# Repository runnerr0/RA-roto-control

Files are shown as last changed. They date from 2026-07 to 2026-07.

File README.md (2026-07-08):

# RA Roto Control

Networked motor-speed controller for **Radiant Atmospheres**. Show-control protocols
(**DMX512, Art-Net, sACN/E1.31**) feed an **ESP32-POE-ISO** that translates them to **RS232 serial**
commands driving a **Roboteq HDC2450** brushed-DC motor controller — with a web interface for setup, DMX
personas, network config, live telemetry, and manual override. Sibling project to [raDMX](../raDMX).

**Everything drives the motor over serial** — and it has proven to be an excellent control interface.
One signed command (`!G 1 <-1000..+1000>`) is speed *and* direction, the controller's own command-loss
watchdog self-stops the motor if the sender goes silent, and it streams back real telemetry (amps,
volts, temp, faults) — all with **no DAC, op-amp, or calibration**. That's why the whole design
converges on one path:

```
DMX512 / Art-Net / sACN ─► ESP32-POE-ISO ─► RS232 serial (!G) ─► HDC2450 ─► roto motor
```

The [host control console](tools/roto-bench/README.md) already drives that serial link on real hardware;
the ESP32 is the networked front-end that will feed the same serial path (a follow-up, pending parts).

## What it does

```
DMX512 / Art-Net / sACN ─► ESP32-POE-ISO ─► MAX3232 ─► RS232 ─► HDC2450 ─► roto motor
                                │  ◄── telemetry (amps, volts, temp, faults) ──┘
                                └──── web UI: config · personas · override · diagnostics
```

- **One motor**, commanded over serial: `!G 1 <-1000..+1000>` — one signed value is speed **and**
  direction (0 = stop). No DAC, no op-amp, no calibration.
- **DMX personas** incl. **ultra-slow modes** (compressed command ranges) + a live **multiplier**.
  See [`docs/PERSONAS.md`](docs/PERSONAS.md).
- **Wired Ethernet + PoE + galvanic isolation** (Olimex ESP32-POE-ISO) for rugged festival deployment.
- **Layered fail-safe** — the HDC2450's own `^RWD` command-loss watchdog stops the motor if the ESP32
  goes silent (works on serial, unlike analog), backed by firmware STOP + slew limiting.
- **Real telemetry** — motor amps, battery voltage, temperature, and fault flags in the web dashboard.

## Hardware

- **Host:** Olimex ESP32-POE-ISO
- **Motor controller:** Roboteq HDC2450 (Motor 1 channel)
- **Link:** ESP32 UART → MAX3232 → HDC2450 RS232 (DB25 pins 2/3), shared ground on pin 5
- **Optional:** KF0602D SSR for remote power-enable; MAX485 + XLR for physical DMX512 input

Full pinout, wiring diagram, BOM, and bring-up checklist: [`docs/HARDWARE.md`](docs/HARDWARE.md).

## Firmware

PlatformIO + Arduino-ESP32. Serial control core, Art-Net/sACN parsers, layered fail-safe, and a minimal
async web dashboard — **compiles clean** for the ESP32-POE-ISO (RAM 13.6%, Flash 67.9%).

```bash
cd firmware
pio run -e olimex_poe_iso            # build
pio run -e olimex_poe_iso -t upload  # flash
```

## Host tools (bench / bring-up)

Python tools that talk to the HDC2450 directly over USB — no ESP32 required — for commissioning and
bench control. Require `pyserial`.

- **[`tools/roto-setup/`](tools/roto-setup/)** — config tool. Read (`--audit`) or write + verify
  (`--apply`, RAM by default) controller configuration from JSON manifests. **Config-only: never issues a
  motor command.** As-found config catalogs live under `captures/`.
- **[`tools/roto-bench/`](tools/roto-bench/)** — a full-featured web **control console** (`roto_bench.py` +
  `ui.html`). Drives Motor 1 over serial with named run modes (**JOG / CRUISE / DRIFT / HOLD**; DRIFT =
  auto slow-sweep patterns, now explicit Run/Stop) and a **HOLD/CREEP** effort control. Layered safety: arm
  toggle, an enforced-and-displayed **speed cap** in every mode, slew, browser deadman, **spacebar E-STOP**,
  a **current governor** (default on — feathers command to hold amps just under the limit instead of
  tripping), a **soft-stop** that halts every mode (incl. DRIFT), plus **overcurrent/stall + temperature +
  I²t auto-trip** and **control-drift detection**. UI is in **percentages** with center-zero sliders,
  comprehensive hover-help, and an operator guide at `/guide`; **pop-out** dashboards (`/graphs`, `/stats`)
  drive a second screen, `--lan` + `/remote` give a phone view, and **config backup/restore** snapshots the
  controller. A **`--sim` preview mode** runs the whole UI with no hardware. **Also a viable standalone
  run-time control path** for a self-contained piece — see [`tools/roto-bench/README.md`](tools/roto-bench/README.md).
- **[`tools/as5600-reader/`](tools/as5600-reader/)** — optional AS5600 magnetic-encoder add-on for
  **closed-loop** feedback. A small Arduino/ESP32 (`as5600_reader.ino`) bridges the I²C encoder to USB
  serial; the console reads real **fixture RPM** (shaft RPM ÷ a configurable gear ratio) and adds a
  **TRUE STALL** trip (commanded but the shaft isn't turning — a check open-loop current alone can't make).
  Ships with a parametric 3D-printed nested self-spacing mount (`as5600_mount.scad` + STLs). See
  [`tools/as5600-reader/README.md`](tools/as5600-reader/README.md).

```bash
pip install pyserial
python3 tools/roto-setup/roto_setup.py --audit      # read controller config (safe)
python3 tools/roto-bench/roto_bench.py              # web console at http://127.0.0.1:8791
python3 tools/roto-bench/roto_bench.py --sim        # try the whole UI with no hardware
```

> **Safety:** the bench console commands a real 2×150 A motor controller. Power the motor from a
> current-limited supply, keep the controller's hardware E-stop reachable, and read
> [`tools/roto-bench/`](tools/roto-bench/) before first use.

## Docs

| Doc | Contents |
|-----|---|
| [`CLAUDE.md`](CLAUDE.md) | Project guide, locked decisions, operational rules |
| [`docs/HARDWARE.md`](docs/HARDWARE.md) | Pinout, MAX3232 wiring, BOM, bring-up checklist |
| [`docs/PERSONAS.md`](docs/PERSONAS.md) | DMX persona definitions + command scaling |
| [`docs/ARCHITECTURE.md`](docs/ARCHITECTURE.md) | Firmware module map, protocols, safety model, roadmap |

## Status

**Serial control + safety proven on hardware — via the host console.** The
[control console](tools/roto-bench/README.md) has matured into a full-featured run-time control surface:
Motor 1 runs over `!G` behind a current governor, soft-stop, an enforced speed cap, and layered auto-trip
protection (overcurrent/stall, temperature, I²t) plus control-drift detection. The optional
[AS5600 encoder](tools/as5600-reader/README.md) adds closed-loop RPM feedback and a true-stall trip.
Telemetry, `ALIM`/`ATGA` config, and the `^RWD` watchdog are all validated. New console/encoder features
are proven in `--sim` and on the bench; the legacy DMX→analog rig is reverse-engineered in
[`docs/LEGACY-WIRING.md`](docs/LEGACY-WIRING.md).

The **ESP32-POE-ISO firmware** (the product — adds Ethernet/PoE + DMX/Art-Net/sACN) compiles clean;
next step is porting the proven console logic into firmware. See [`docs/ARCHITECTURE.md`](docs/ARCHITECTURE.md).

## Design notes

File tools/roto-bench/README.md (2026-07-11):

# RA Roto — Control Console (`roto-bench`)

A host-side (macOS / Linux) web console that drives the **Roboteq HDC2450, Motor 1**, directly over
USB serial — **no ESP32 required**. It began as a bench bring-up instrument and has grown into a
**viable standalone run-time control path** for a self-contained rotating piece (see
[Running from this console](#running-the-show-from-this-console)).

```
browser (localhost:8791) ──HTTP──► roto_bench.py ──USB serial──► HDC2450 ──► Motor 1
        control + telemetry              (owns the port)         !G / ?… / ^…
```

stdlib + `pyserial` only, no build step:
- **`roto_bench.py`** — serial worker + web server + optional encoder reader (the engine).
- **`ui.html`** — the operator console (served at `/`).
- **`guide.html` · `graphs.html` · `stats.html` · `remote.html`** — the operator guide (`/guide`),
  pop-out live charts (`/graphs`), big telemetry tiles (`/stats`), and a touch phone view (`/remote`).

---

## Quick start

```bash
./run.sh                         # finds Python 3.6+, installs pyserial if needed, launches
# — or manually —
pip install pyserial
python3 roto_bench.py            # auto-detects the HDC2450 USB port
# open http://127.0.0.1:8791
```

It starts **DISARMED**. Pick a run mode → **ARM** → drive. Power the motor from a **current-limited
supply** and keep the controller's hardware E-stop reachable.

### Flags (all pass through `run.sh` too)

| Flag | Effect |
|---|---|
| `--port PORT` | Pin the serial port (auto-detected otherwise). |
| `--cap N` | Initial speed cap in raw command units `/1000` (default `150` = 15%). |
| `--sim` | **Preview mode** — run the whole UI on synthetic telemetry, **no hardware**. Validates logic/UI, not real motor physics. |
| `--webport N` | HTTP port (default `8791`). |
| `--host ADDR` / `--lan` | Bind address; `--lan` = `--host 0.0.0.0` to reach the console from a phone/tablet on the LAN. Prints a `/remote` URL. |
| `--encoder PORT` | Enable the optional AS5600 encoder bridge at boot (also toggle it live in the UI). |
| `--gear R` | Gear ratio — encoder-shaft revs per fixture rev (default `1.0`). |

## Compatibility (older Macs)

Designed to run on legacy machines — there's **no build step, no native code, and one pure-Python
dependency**, so CPU architecture and OS age barely matter. `run.sh` handles the fiddly parts.

| Piece | Minimum | Notes |
|---|---|---|
| **Python** | **3.6+** | `ThreadingHTTPServer` has a 3.6 fallback; only `pyserial` is required. |
| **Browser** | **Safari 10+** (2016) / any modern Chrome or Firefox | UI avoids ES2020 syntax (no `?.`/`??`) and uses `XMLHttpRequest`, so old Safari doesn't choke. |
| **Serial** | USB CDC (`/dev/cu.usbmodem*`) | Auto-detected; pass `--port` to pin it. |

Kept legacy-safe deliberately: no transpiler, no framework, `ui.html` is served as-is and re-read per
request. If you touch the UI, stick to ES6 (arrow functions/template literals are fine) and avoid
`?.`, `??`, and other ES2020+ features so it keeps running on old Safari.

---

## Run modes

Pick the mode that matches what you're doing; each sets the right safety behavior for you.

| Mode | Behavior | Use for |
|---|---|---|
| **JOG** | Hold the slider to run; release = stop. | Setup, positioning, testing. |
| **CRUISE** | Set a speed; it holds. Stall-protected. | Steady running. |
| **DRIFT** | Two-phase self-running sweep (**Run/Stop** — see below). Stall-protected. | Ambient / atmospheric motion. |
| **HOLD** | Maintain position under load; stall-trip off, temperature/I²t still guard. | Holding against a load. |
| **CREEP** | Very slow under load; stall-trip off, anti-stiction kick on start. | Slow loaded creep. |

### DRIFT (two-phase, Run/Stop)
Entering DRIFT arrives **halted** — it does *not* auto-run. Set the pattern, then press **▶ Run drift**;
the global **Stop** halts it. The command is generated server-side (`/api/drift`), cycling:
hold **Side A** (`ta` s) → ramp to **Side B** (`ramp` s) → hold **Side B** (`tb` s) → ramp back → repeat.
- **Side A / Side B speed** — the two target speeds (%, center-zero: right = fwd, left = rev).
- **hold A / hold B** — seconds to dwell at each side.
- **ramp** — seconds to ease between the two sides (`0` = snap).

Every side is clamped to the **speed cap** — set the cap ≥ the larger side or the peaks clip.

---

## Safety (layered)

Fastest / most-local first — a fault stops the motor, it doesn't run it:

1. **PSU current limit** — physical, reset-proof. The real ceiling.
2. **HDC2450 `ALIM` foldback** — controller caps motor current (we run 5 A).
3. **`^RWD` watchdog** — the console streams `!G` every ~66 ms; if the process dies, the controller
   self-stops in ~0.5 s.
4. **Current governor** *(RUN modes, **default ON**)** — closed loop on motor current: feathers the
   command to hold amps just under ~0.85×`ALIM`, so the motor **rides** the ceiling instead of slamming
   it and breaking free. **While the governor is on, the stall/overcurrent trip is suppressed** — the
   governor owns current limiting; I²t + temp + `ALIM` foldback are the backstops. Toggle + "% of limit"
   in **⚙ Settings** (`/api/governor`).
5. **Stall / overcurrent trip** *(RUN modes, **only when the governor is OFF**)* — amps held near the
   limit for `trip_ms` → stop + disarm.
6. **Temperature trip** — max controller temp ≥ threshold → stop. Jam/hold agnostic.
7. **I²t overload trip** — leaky current²·time budget → stop. Catches "holding too hard, too long."
   On by default; the **I²t checkbox** in Settings → Protect disables it (the budget value is kept, the
   accumulator clears) when the proxy fights a legitimately heavy load — temperature stays the real guard.
8. **TRUE STALL trip** *(optional encoder)* — commanded ≥ 10% but the shaft reads ~0 RPM → stop.
   Suppressed in HOLD/CREEP (which legitimately sit near 0 RPM). See the encoder section.
9. **Control-drift alarm** — see below.
10. **Operator layer** — arm toggle, hold-to-run (JOG), browser deadman (JOG), speed cap + slew,
    **soft-stop latch**, **E-STOP** (button or **spacebar**).

On any trip: command → 0, motor **disarmed**, latched until the operator clears it. A red banner +
audible alarm + timestamped alert log. The command card also shows **why** output is held at 0
(DISARMED / DEADMAN / STOPPED / TRIPPED / E-STOP), so "armed but not moving" is never a mystery.

> **Soft-stop latch.** The **Stop** button (`/api/stop`) forces output to 0 in **every** mode — including
> a running DRIFT — while staying **armed**; status shows **STOPPED**. Any fresh command (slider, Go,
> Run drift) releases it. Distinct from E-STOP, which also disarms and latches.

> **Jam vs. hold:** open-loop (no encoder) can't tell a jam from a loaded hold by current alone.
> That's why RUN modes stall-trip on current while HOLD relies on temperature + I²t. The real fix is
> an encoder (closed loop) — the HDC2450 has the inputs for it.

---

## Operating the console (UI)

- **Everything command-related is in percent (0–100%)**, not raw −1000…1000.
- **Center-zero sliders** (jog + drift Side A/B) fill outward from center — green forward, amber reverse.
- **Speed cap enforced in every mode** *and* surfaced: the slider range and the exact-speed box are
  limited to the cap, and a **⚠ at speed cap** note shows when pinned. The engine also clamps to ±cap.
- **HOLD / CREEP effort control** replaces the coarse slider with a Fwd/Rev toggle + a dial scoped
  `0..cap` + fine `−5/−1/+1/+5` nudges and a large "N% fwd/rev" readout — for fine effort in the low band.
- **Arm is a toggle switch** (slides on/off), not a state-labeled button.
- **? Help** toggle in the top bar: point at any control for an inline explanation. Full operator guide
  at **`/guide`**.
- **Top bar**: status · live amps/cmd · ARM · Help · Guide · **E-STOP** (isolated far-right). Clear E-Stop
  / Reset Trip appear only when relevant. **Spacebar = E-STOP** (unless a field is focused).

## Second screen & remote access

- **⧉ Pop out** opens **`/graphs`** (live motion / current / all-telemetry charts) and **`/stats`**
  (big color-coded telemetry tiles) in their own windows — drag either to a second monitor.
- **`--lan`** (or `--host 0.0.0.0`) exposes the console on the network; **`/remote`** is a
  touch-optimized phone view (monitor + E-STOP / Arm / Stop). `--webport N` changes the port. LAN motor
  control is a deliberate security tradeoff — trusted network only.
- **`--sim`** runs the entire UI on synthetic telemetry with **no hardware** — validates logic and the
  UI, not real motor physics.

## Optional: AS5600 encoder (real motion feedback)

An **AS5600 magnetic encoder** on a small Arduino/ESP32 I²C→USB bridge adds real shaft sensing. Enable it
in **⚙ Settings → Encoder** (port + gear ratio + a live debug readout), or at boot with
`--encoder PORT --gear R`. It's a pure sensor — it never commands the motor — and it adds:

- **Fixture RPM** — shaft RPM ÷ gear ratio (the big-wheel speed).
- **TRUE STALL trip** — commanded ≥ 10% but the shaft reads ~0 RPM → stop. The motion check open-loop
  current can't make. Suppressed in HOLD/CREEP.

Endpoints `/api/encoder`, `/api/serial_ports`. Hardware, firmware, and 3D-printed mount:
[`../as5600-reader/`](../as5600-reader/) (`as5600_reader.ino`, `as5600_mount.scad`). This is the interim
toward full controller-side closed loop (encoder on the HDC2450 ENC inputs + `MMOD`).

---

## Advanced — controller profile & control drift

The **Advanced** section (collapsed by default) live-edits the HDC2450's **own** configuration —
`ALIM`, `MXPF/MXPR`, `RWD`, `ATRIG/ATGA/ATGD` — written to controller **RAM** and read back to verify.
Each parameter is described inline. `Save to flash` persists RAM → EEPROM.

**Control-drift detection.** The console continuously compares the controller's live `ALIM`, `RWD`,
`AINA 3`, `AINA 4` against an expected safe baseline. If they diverge — most commonly because a
**controller reset reverted the RAM config** back to factory (100 A limit, analog command re-enabled) —
it raises a **CONTROL DRIFT** critical alarm. **Re-apply safe profile** restores the baseline in one
click. Deliberate edits you make become the new baseline, so it only alarms on drift you didn't intend.

> RAM config is lost on any controller reset. For a run, `Save to flash` so it survives a power cycle.

**Config backup / restore.** *Config snapshot* captures the controller's **current** config as a restore
point and writes it back with one tap — instant recovery if the config drifts or a power cycle reverts it.
**Backup** also downloads a `.json`; **Load file** restores from a previously saved one. Complements
*Re-apply safe profile* (which restores the fixed safe baseline).

---

## Slow-loaded operation (CREEP + characterization)

Very slow motion under load is the hardest regime: open-loop command ≈ voltage only tracks speed at
light load, and slow + loaded draws **high current at near-zero motion** — which electrically looks like
a stall and would false-trip the current-stall protection. Two tools address this today:

- **CREEP mode** — a latched slow mode that **suppresses the current-stall trip** (temperature + I²t
  still protect), plus an **anti-stiction kick**: a brief breakaway boost (`kick` level for `ms`) on
  start-from-stop to overcome static friction, then it settles to your set speed.
- **Characterization log** — records command · amps · volts · temp to CSV (`logs/`, ~5 Hz). Use it to
  find the **breakaway command**, the current at slow-loaded, and whether it creeps smoothly. Measure
  before tuning.
- **Characterization sweep** — an operator-triggered routine (ARM required; aborts instantly on any
  trip / disarm / E-STOP; clamped to the speed cap) that steps the command through a range, records the
  settled amps per step, and computes the **breakaway command** + a **suggested CREEP kick**. Save
  results as named **presets** (`presets/`); the most recent loads on startup as a baseline for
  comparison (display only — it never moves the motor).

These make open-loop slow-loaded *usable*. The **proper** fix is closed loop: add an **encoder** to the
HDC2450's ENC inputs, set `MMOD` = closed-loop speed, and `!G` then commands a target RPM the controller
holds under varying load — which also makes stall detection unambiguous. Encoder + **gearing** (the
highest-leverage mechanical move) are hardware follow-ups (pending parts); CREEP + logging cover the
interim. See the slow-speed plan in the project docs.

## Tuning for a loaded roto

A large, slow, **unbalanced** roto (one that lifts a mass up one side) is the hard case: it draws
**current that varies with angle** — highest while lifting, low or regenerative on the way down. The
number that matters is the **peak-lift current**, and current *is* torque, so if the current limit is
below what the peak needs, it stalls at the hardest angle ("won't lift").

### The workflow

1. **Be on the real supply**, not a current-limited bench PSU — and **fuse & wire** for the current
   you'll run. With a big supply the controller `ALIM` + the trips are now your safety, not the PSU.
   Keep the hardware E-STOP reachable.
2. **Run the guided lift test** (its own card). It holds a slow command and steps `ALIM` up rung by
   rung until measured amps fall *below* the limit — the moment the motor breaks free — and reports
   the **load current**. It requires ARM, aborts on any trip/disarm/E-STOP, auto-stops on over-temp,
   never exceeds your ceiling, and **restores the safe limit** on any non-success stop.
3. **Set `ALIM ≈ peak-lift × 1.3`** in the Advanced profile editor (the test prints the suggestion).
   That gives torque headroom at the worst angle without running wide open.
4. **Verify under load**: run it loaded at your target speed for a few minutes with **CREEP** (stall
   trip suppressed; temp + I²t still guard) and watch the **Max temp** stat. Temp **stabilising** =
   good. Temp **climbing** = you're over the motor's continuous rating at this duty.
5. **Set the guards** with the loaded numbers: stall trip *above* peak-lift, a temperature trip below
   the motor's limit, an I²t budget that tolerates normal lifting but catches a jam. Tune the **CREEP
   kick** to just above the breakaway (from the characterization sweep) so it starts cleanly.
6. **Save to flash** once dialled, so a controller reset can't revert it (and the control-drift alarm
   will catch it if it does).

### When more current isn't the answer

If the lift test hits the ceiling without lifting, or step 4 shows temperature that keeps climbing,
the motor is telling you it's past its **continuous** rating at that duty (slow = no cooling airflow,
near-locked-rotor heat). The real fixes are **more gear reduction** (the highest-leverage move — less
motor current for the same load) or a **run/rest duty cycle** — not just raising `ALIM`. And once an
**encoder** is fitted, closed-loop speed control does this angle-by-angle automatically: it pours in
current at the hard lifting angle and backs off on the descent.

## Running the show from this console

This console is a genuine control path, not only a bench tool — for a **self-contained rotating piece
that doesn't need lighting-console (DMX) integration**, you can run the whole show from it: set a
**DRIFT** pattern (or a CRUISE speed), ARM, and let it run.

To do that reliably:
- **Run on an always-on host** — a mini PC / Raspberry Pi / NUC, **not a laptop that sleeps**. Sleep
  suspends the process → the `^RWD` watchdog stops the motor (safe, but it stops).
- **`Save to flash`** the safe profile so a controller glitch can't revert to 100 A / analog.
- **Current-limited supply + hardware E-stop** wired, always.
- **Good USB cable**; the worker auto-reconnects if the link drops (and the watchdog covers the gap).
- Access is **localhost-only** by default. `--lan` exposes it for phone/tablet control (`/remote`) — a
  deliberate security decision for motor control; do it on a trusted network only.

### vs. the ESP32-POE-ISO firmware (the product)
| | This console | ESP32 firmware |
|---|---|---|
| Host needed | yes (USB-tethered computer) | no (standalone) |
| Show-control input | none (manual / DRIFT) | DMX512 / Art-Net / sACN |
| Network | localhost / LAN | wired Ethernet + PoE + isolation |
| Best for | self-contained piece, bring-up, diagnostics | DMX-integrated installs, rugged deploy |

Both share the same command/telemetry/safety logic — this console proved it on hardware first.

---

## What we've figured out (hardware findings)

- **Serial control works end to end.** Motor 1 runs from `!G 1 <-1000..1000>` over USB; telemetry
  (`?A ?V ?T ?FF ?AI ?PI ?AIC`) reads back. Baud 115200 8N1 confirmed.
- **The legacy rig was DMX → Northlight "Decode8" → 0–5 V analog → HDC2450.** Fully reverse-engineered
  in [`docs/LEGACY-WIRING.md`](../../docs/LEGACY-WIRING.md); the missing analog ground (Decode8 `G` →
  DB25 pin 5) was the dead-rig cause.
- **As-found controller config** cataloged in [`../roto-setup/captures/`](../roto-setup/captures/):
  factory command priority (Serial > RC > Analog), both `AnaCmd` inputs (pins 4 & 17 = ANA3/ANA4)
  targeting Motor 1, real protection (100 A limit, 45 V OV, 5 V UV).
- **`ALIM` accepts a true 5 A limit** (the datasheet's 10 A floor didn't bite).
- **`ATGA` decoded** (`^ATGA cc (aa + mm)`, `mm = mot1·16`): `17` = safety-stop on Motor 1. `ATRIG`
  must be set **below** `ALIM`, which is what makes controller-side stall detection work with foldback.
- **RAM config reverts on controller reset** → the control-drift alarm exists to catch it.

---

## Files
- `roto_bench.py` — engine (worker + HTTP + encoder reader). Flags: `--port`, `--cap`, `--sim`,
  `--webport`, `--host`, `--lan`, `--encoder`, `--gear`.
- `ui.html` — operator console (`/`). Re-read per request — edit freely, no restart needed.
- `guide.html` · `graphs.html` · `stats.html` · `remote.html` — operator guide (`/guide`), pop-out
  charts (`/graphs`), telemetry tiles (`/stats`), phone view (`/remote`).
- `run.sh` — portable launcher (finds Python 3.6+, installs pyserial); passes all flags through.
- `presets/` · `logs/` — saved characterization presets and CSV run logs.

Optional encoder hardware/firmware/mount: [`../as5600-reader/`](../as5600-reader/).
Config commissioning (read/write the controller from JSON manifests, config-only) lives in the sibling
[`../roto-setup/`](../roto-setup/).

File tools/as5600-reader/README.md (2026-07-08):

# AS5600 Encoder Add-on (`as5600-reader`)

An **optional** magnetic-encoder add-on that gives the RA Roto control console real closed-loop
motion feedback — **actual RPM** of the fixture, and a **TRUE STALL** trip. Everything here is off by
default; you **enable and debug it entirely from the console UI** (⚙ Settings → Encoder card).

## Why

The console drives the HDC2450 **open-loop**: `!G` command ≈ voltage, no idea what the shaft is doing.
Current alone can't tell a **jam** from a **loaded hold** — both draw amps at near-zero motion. An
AS5600 on the shaft closes that gap: it reports whether the thing is *actually turning*, so the console
can show true RPM and stop the motor when it's commanded to move but isn't.

## Architecture — the simplest path

The AS5600 is **I2C**, and a laptop has no I2C. So a small MCU bridges it: a cheap Arduino / ESP32 /
Pico reads the AS5600 over I2C and streams angle + RPM over **USB serial** — a second serial port the
console reads alongside the HDC2450 port. (More robust than a USB-I2C dongle, and you probably have a
spare board.)

```
AS5600 ──I2C──► MCU (bridge) ──USB serial──► laptop ──► roto console
                as5600_reader.ino            (EncoderReader thread)
```

---

## Firmware — `as5600_reader.ino`

Reads the AS5600 (I2C addr **0x36**, `RAW_ANGLE` reg **0x0C**, 12-bit → **4096 counts/rev**),
**unwraps** each reading across the 4095↔0 seam into a cumulative position, computes **SIGNED RPM**
(direction-aware — the absolute-angle sensor gives sign for free), and reads the **MD** (magnet-detect)
bit from the status register (0x0B).

- **Stream:** ~10 Hz, **115200 baud**, one line per report:

  ```
  ANG=<0-4095> POS=<cumulative_counts> RPM=<signed float> MAG=<0|1> STALL=<0|1>
  ```

  (`STALL` here is just the firmware's own `|rpm| < 0.5` flag; the console does the real
  commanded-vs-moving trip logic.)

- **Wiring** (from the sketch header; check your board's I2C pins):

  | AS5600 | MCU |
  |--------|-----|
  | VCC | **3.3 V** |
  | GND | GND |
  | SDA | board SDA (Uno/Nano A4, ESP32 GPIO21, Pico GP4) |
  | SCL | board SCL (Uno/Nano A5, ESP32 GPIO22, Pico GP5) |

  The AS5600 is a **3.3 V** part — on a 5 V board (Uno/Nano) **level-shift SDA/SCL** or use a
  3.3 V-logic board / ESP32 / Pico. The **diametrically-magnetised** magnet mounts on the shaft's
  **END face**, centred on the die, **~1–2 mm** gap.

---

## Console integration

Everything is driven from the console — no config files.

- **⚙ Settings → Encoder card:** an **enable** toggle, a **port** dropdown (populated from
  `/api/serial_ports`), a **gear ratio** field, an **Apply** button, and a live **debug readout**:
  present/stale, magnet OK/not-detected, shaft RPM → fixture RPM, cumulative position, and the raw line.
- **Gear ratio.** The encoder rides a small cog driving the big wheel, so the shaft spins faster than
  the fixture: **fixture RPM = shaft RPM ÷ gear ratio**. Set the ratio to the encoder-shaft revs per one
  fixture revolution. The **Speed** telemetry row and the stats pop-out show real **fixture RPM** whenever
  the encoder is live (instead of the controller's `?S`).
- **TRUE STALL trip.** When commanding **≥10%** (`ENC_STALL_CMD = 100`) but the shaft reads **<1 RPM**
  (`ENC_STALL_RPM`) for **>1.2 s** (`ENC_STALL_MS`) — in a **RUN** intent, armed, not already stopped —
  the console stops the motor. This is the motion check open-loop current can't make. It's **suppressed
  in HOLD/CREEP**, which legitimately sit near 0 RPM under load. If the encoder line goes silent for
  >1.5 s (`ENC_TIMEOUT`) it's treated as absent and the trip disengages (fail-safe, not fail-active).

- **Endpoints:** `/api/encoder?on=&port=&ratio=` (enable / port / gear ratio) and `/api/serial_ports`
  (candidate ports for the dropdown).
- **Boot flags:** `--encoder <PORT>` (enable + pin the port at start) and `--gear <ratio>`.

---

## The 3D-printed mount — `as5600_mount.scad`

Parametric OpenSCAD. **NESTED, self-spacing** design: the two printed parts set the sensor-to-magnet
**air gap by nesting together** — the L-bracket does *not* set the gap.

- **Magnet carrier** — grips the shaft (M3 set screw). A **solid floor** (`bore_floor`) above the shaft
  bore ties a raised **pilot** into the body; the pilot holds the **5×2 diametric magnet** on-axis in a
  pocket at its top. The step where the pilot meets the wider body is the **shoulder**.
- **Sensor holder** — cups over the pilot: its bore is a **register** (`hub_fit`) that centres the
  AS5600 chip over the magnet, and its hub bottom **seats on the shoulder**. That seat *is* the spacer —
  it fixes the board exactly `air_gap` above the magnet, and the gap stays constant even if the shaft
  wobbles (the board rides the holder, the holder rides the carrier). The board mounts **chip-down**
  over an open central window so the die sees the magnet. The carrier **spins under** the holder; they
  rub at the seat (fine for a slow roto — a thrust washer/bearing can drop onto the pilot later).
- **Gap gauge** — a shim exactly `air_gap` thick to confirm the seated gap.
- **L-bracket** — any spare; it only pins the holder's **anti-rotation ear** (retention, not spacing).

**Board:** the 23×23 mm AS5600 module (mounting holes 16 mm c-c, 3.5 mm). **Fits** (tune to your
printer): `shaft_fit` **0.45** and `magnet_fit` **0.25** (printed-to-metal, ABS shrink room);
`hub_fit` **0.25** (printed-to-printed register — deliberately tight for concentricity, ~0.5 mm total
slop so it spins yet stays centred). Print orientations are baked into the `part` selector
(`"carrier"` / `"holder"` / `"gauge"`); exported meshes are in **`stl/`** (`as5600_carrier.stl`,
`as5600_holder.stl`, `as5600_gauge.stl`).

---

## Bring-up

1. **Flash** `as5600_reader.ino` to the MCU.
2. **Wire** the AS5600 (3.3 V, level-shift on a 5 V board), magnet on the shaft end face ~1–2 mm.
3. **Plug** the MCU into the laptop.
4. In the console: **enable** the encoder, **pick the port**, **set the gear ratio**, Apply.
5. **Spin the shaft by hand** and confirm RPM / position move and **magnet = OK**.

For the mount, **print the carrier + gauge first** to check the shaft and magnet fits, then print the
holder.

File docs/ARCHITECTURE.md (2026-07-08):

# Firmware & System Architecture

ESP32-POE-ISO firmware bridging show-control protocols → **RS232 serial** → HDC2450. Built on
PlatformIO + Arduino-ESP32, following raDMX patterns.

---

## Module map

```
        ┌──────────────────────── Network (Ethernet, isolated PoE) ─────────────────────┐
        │                                                                                │
   Art-Net rx ──┐                                                                        │
   sACN/E1.31 ──┼─► InputMux ──► PersonaEngine ──► SafetyStage ──► SerialController ─UART─┼─► MAX3232 ─► HDC2450
   DMX512 rx  ──┘        ▲          (→ [-1,1])      (slew + STOP)   (!G / ?A?V?T?FF / ^RWD)│      ▲
                         │                                                │                │      │
                    OverrideCtl                                     Telemetry ◄────────────┼──────┘
                         ▲                                                │                │
                    WebServer (ESPAsyncWebServer + WebSocket) ◄───────────┘                │
                         │                                                                 │
                    ConfigStore (NVS) · OTA                                                │
        └───────────────────────────────────────────────────────────────────────────────┘
```

### Modules
- **InputMux** — arbitrates the command source (priority **Override > DMX512 > sACN > Art-Net**),
  tracks per-source liveness, normalizes the active DMX slot(s) to `d ∈ [0,1]`.
- **PersonaEngine** — persona math (`docs/PERSONAS.md`) → command in **[-1,1]** (0 = stop).
- **SafetyStage** — deadband is in PersonaEngine; here: slew-rate limit, clamp, and STOP substitution
  when no live source / e-stop. Secondary fail-safe.
- **SerialController** — `!G 1 <-1000..1000>` (sent continuously at 20 Hz → also feeds the watchdog),
  round-robin telemetry queries, `^RWD`/`^ECHOF` config, online detection.
- **Telemetry** — motor amps / battery V / temp / fault flags parsed from `?A ?V ?T ?FF`.
- **NetworkManager** — Olimex ETH bring-up + link/IP events.
- **ArtnetInput / SacnInput** — ArtDMX + E1.31 parsers over AsyncUDP.
- **ConfigStore** — versioned Settings blob in NVS.
- **WebServer / WebSocket** — config, override, live telemetry dashboard.

---

## Protocols

| Protocol | Transport | Library | Notes |
|---|---|---|---|
| **HDC2450 control** | RS232 (MAX3232) on UART1 | native | `!G` commands + `?…` telemetry, 115200 8N1 |
| **DMX512** | RS485 (MAX485) | `esp_dmx` (TODO) | Physical XLR input, GPIO35, optional |
| **Art-Net** | UDP 6454 | AsyncUDP (built-in) | Universe configurable |
| **sACN / E1.31** | UDP 5568 multicast | AsyncUDP (built-in) | Universe + multicast join |

---

## Safety model (layered)

The serial pivot upgraded this materially — the HDC2450's command-loss watchdog only works on serial:

1. **HDC2450 `^RWD` watchdog (primary):** controller self-stops if it doesn't receive a command within
   500 ms — independent of our firmware. This is why serial beats analog for a motor.
2. **Continuous send:** `SerialController` emits `!G` at 20 Hz, so a hung/crashed ESP simply stops
   feeding the watchdog → controller stops.
3. **Firmware STOP (secondary):** `SafetyStage` drives command → 0 on boot, Ethernet link-loss,
   source-stale, or e-stop; slew-rate limits every change.
4. **ESP task watchdog:** hang → reset → boot re-commands STOP before powering the controller.
5. **Optional hardware E-stop** (GPIO39) → STOP + drops the PwrCtrl SSR.
6. **Optional PwrCtrl SSR** (GPIO32) → remote/auto power-down of the controller.

Boot order is safety-ordered: serial up → command STOP → *then* enable PwrCtrl.

---

## Web interface

Single-page dashboard (embedded now; full LittleFS SPA in Phase 3). WebSocket live data.
Sections: **Command** (source, input %, target/output %, fail-safe state), **Controller** (serial
online, motor amps, battery V, temp, fault flags), **System** (Ethernet, uptime), **Override**
(takeover toggle + slider: 0 = rev, 50 = stop, 100 = fwd). Phase 3 adds persona editor, network
config, calibration-free diagnostics, OTA.

---

## Two control paths

The serial command path, telemetry, and layered safety model are **proven on real hardware today** —
but via the **host control console** ([`tools/roto-bench/`](../tools/roto-bench/)) over USB, not yet the
ESP32. The console validated `!G` control, `?…` telemetry scaling, the `^RWD` watchdog, `ALIM`/`ATGA`
config, and the stall/temperature/I²t trips before any of it goes into firmware — and has since matured
into a full run-time control surface (a **current governor** that feathers command under the limit
instead of tripping, a **soft-stop** across every mode, an **enforced + displayed speed cap**, and
control-drift detection). The optional **AS5600 magnetic encoder** ([`tools/as5600-reader/`](../tools/as5600-reader/))
closes the loop: real **fixture RPM** (shaft RPM ÷ gear ratio) and a **true-stall** trip (commanded but
the shaft isn't turning) — the unambiguous jam-vs-hold check open-loop current alone can't make. It also
stands on its own as a runtime control path for a self-contained piece (DRIFT patterns, no DMX needed).
The ESP32 firmware is the **product** target — adds wired Ethernet/PoE, isolation, and DMX/Art-Net/sACN
input — and reuses the same command/telemetry/safety logic the console proved. The ESP32 build is a
**follow-up component, pending parts** — the console (run on an always-on host) covers running the piece
in the meantime.

## Roadmap

- **Phase 0 — Planning + firmware scaffold.** ✅ Docs + serial control core, compiles clean.
- **Phase 1 — Serial bench bring-up.** ✅ *(host console)* link check, `^RWD`, telemetry.
- **Phase 2 — Motor-in-the-loop.** ✅ *(host console)* live `!G`, direction/speed/slew, 5 A limit, trips,
  current governor, soft-stop, enforced speed cap, and optional AS5600 closed-loop RPM + true-stall.
  → **Next:** port the proven command/telemetry/safety logic into ESP32 `SerialController`/`SafetyStage`.
- **Phase 3 — Protocols + web UI (ESP32).** Art-Net + sACN + optional DMX512; dashboard; override; OTA.
- **Phase 4 — Telemetry hardening.** Fault-flag decoding + reconnect (mostly validated on the console).
- **Phase 5 — Field hardening.** Enclosure, DB25 hood, E-stop + PwrCtrl SSR, deployment test.

---

## Confirmed on hardware (via the console)
- ✅ HDC2450 serial = **115200 8N1**; `?FID` and config queries respond.
- ✅ `?A` amps ×10 and `?V` battery ×10 scaling confirmed; `?FF` fault flags decoded.
- ✅ `ALIM` accepts a true **5 A** limit; `ATGA 17` = safety-stop M1; `ATRIG` must be below `ALIM`.
- ✅ Command priority is factory default **Serial > RC > Analog** (serial wins; no config change needed).

## Still open before ESP32 bring-up
- Verify GPIO13/14 (UART) free on the exact Olimex ESP32-POE-ISO revision.
- Whether physical DMX512 input is needed for v1 or Art-Net/sACN only.
- Whether the ESP32 build carries the optional **AS5600 encoder** (closed loop, unambiguous
  jam-vs-hold) — already proven on the console via [`tools/as5600-reader/`](../tools/as5600-reader/).

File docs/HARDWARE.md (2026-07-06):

# Hardware — Wiring, BOM & Bring-up

Host: **Olimex ESP32-POE-ISO**. Motor controller: **Roboteq HDC2450** (Motor 1 channel).
Control path: **RS232 serial** via a **MAX3232** level shifter.

---

## 1. HDC2450 serial interface facts (from datasheet v1.2 + Roboteq command set)

| Fact | Value | Source |
|---|---|---|
| Serial pins (DB25) | **pin 2 = TxData**, **pin 3 = RxData**, true RS232 levels | Table 4 |
| Ground pins (DB25) | 1, 5, 9, 13 | Table 4 |
| Regulated 5V out | DB25 pin 14 / pin 25 (powers the SSR input, §5) | Table 4 |
| Default baud | 115200, 8N1 (set to match Roborun+) | Roboteq serial spec |
| Speed command | `!G <ch> <-1000..+1000>` — signed: -1000 rev, 0 stop, +1000 fwd | Roboteq command set |
| Command-loss watchdog | `^RWD <ms>` — controller stops motor if silent this long (**serial only**) | Features List |
| Command priority | RS232 → RC → Analog (serial wins) | "Default I/O Configuration" |
| Telemetry queries | `?A` amps, `?V` volts, `?T` temp, `?FF` fault flags, `?S` speed | Roboteq command set |
| Abs max on signal pins | 15V (RS232 pins spec'd for external ±15V) | Table 6 |

> Commands terminate with **CR (`\r`)**. We send `^ECHOF 1` (echo off) at connect for clean reply
> parsing, and `^RWD 500` so the controller self-stops within 500 ms of losing our command stream.

---

## 2. ESP32-POE-ISO pin plan

**Ethernet RMII reserves — NEVER reuse:** GPIO 0,12,17,18,19,21,22,23,25,26,27.

| Function | GPIO | Notes |
|---|---|---|
| HDC2450 UART **TX** | **GPIO14** | → MAX3232 T1IN → DB25 **pin 3** (controller Rx). Output-capable, non-strapping. |
| HDC2450 UART **RX** | **GPIO13** | ← MAX3232 R1OUT ← DB25 **pin 2** (controller Tx). Non-strapping. |
| DMX512 input (RS485 RO) | **GPIO35** | Optional physical DMX; input-only, UART RX via matrix. |
| PwrCtrl enable | **GPIO32** | → S8050 → KF0602D SSR (§5). |
| E-stop / deadman | **GPIO39** | Optional; input-only; external pull-up. |
| Status LED | **GPIO33** | Non-strapping. |

Firmware uses **UART1** (`HardwareSerial(1)`) remapped to GPIO13/14. Verify these are free on your
exact Olimex revision before soldering.

---

## 3. Serial link — MAX3232

```
  ESP32 GPIO14 (TX) ──► T1IN   T1OUT ──► DB25 pin 3   (HDC2450 RxData)
  ESP32 GPIO13 (RX) ◄── R1OUT  R1IN  ◄── DB25 pin 2   (HDC2450 TxData)
  ESP32 3V3 ─────────► VCC     GND  ──► signal ground (DB25 pin 5)
                        (4× 100nF charge-pump caps per MAX3232 datasheet)
```
Most MAX3232 breakout modules include the four charge-pump capacitors. Powered at 3.3V from the ESP,
its logic side is 3.3V-clean; its line side drives proper RS232 to the HDC2450.

---

## 4. Grounding

- ESP32 is **PoE-powered and galvanically isolated** from the network; its ground references the
  HDC2450 signal ground.
- **Tie ESP GND ↔ MAX3232 GND ↔ DB25 pin 5 only.** Per datasheet **Note 6**, do NOT run a second
  ground from the I/O connector to battery minus — that creates a ground loop through the 2×150A
  motor power path.
- The optional PwrCtrl SSR (§5) is isolated, so its battery-domain side never touches signal ground.

---

## 5. Power-enable (PwrCtrl) via KF0602D SSR — optional, recommended

Lets the ESP32 (and E-stop logic) power the HDC2450 on/off remotely. **KF0602D**: control 3–32VDC
(1.5 kΩ input), isolated output 3–60VDC / 2A, 80V blocking. HDC2450 idle draw (~150mA @ ≤50V) sits
far inside rating — no heatsink needed.

**Drive the SSR input from 5V (not 3.3V) for margin**, buffered by the **S8050**:
```
  5VOut (pin14) ──► SSR IN(+)
                    SSR IN(−) ──► S8050 collector
  GPIO32 ──[1kΩ]──► S8050 base      (10kΩ base→GND pulldown = off at boot)
                    S8050 emitter ──► signal GND (DB25 pin5)
```
**Output side (two-layer safety):** keep the mandatory manual **SW1** as master cutoff; put the SSR
in series with it: `VBat(+) → SW1 → SSR OUT → HDC2450 Yellow/PwrCtrl`. Controller powers up only when
SW1 closed **and** the ESP asserts the SSR. ESP dead/reset → SSR opens → controller powers down.

---

## 6. Wiring diagram (bench bring-up)

```
 ┌────────────────────────────────────────────────────────────────────────────┐
 │  Olimex ESP32-POE-ISO                    ┌──────────┐                         │
 │                                          │ MAX3232  │                         │
 │  GPIO14 (TX) ───────────────► T1IN ─────►│          │──T1OUT──► DB25 pin 3 ──┐ │
 │  GPIO13 (RX) ◄─────────────── R1OUT ◄────│          │◄─R1IN─── DB25 pin 2 ──┤ │
 │  3V3 ────────────────────────► VCC       │          │                        │ │
 │  GND ────────────────────────► GND ──────┴──────────┴──► DB25 pin 5 (GND) ───┤ │
 │                                                                              │ │
 │                                                              ┌───────────────▼─┐
 │  GPIO32 ─► S8050 ─► KF0602D SSR ─► [VBat→SW1→SSR→Yellow]     │  Roboteq HDC2450 │
 │  GPIO39 ◄─ E-stop (optional)                                 │  M1+/M1- ─► Motor│
 │  GPIO35 ◄─ MAX485 ◄─ DMX512 XLR (optional)                   └──────────────────┘
 └────────────────────────────────────────────────────────────────────────────┘
       Ethernet + power in over one isolated PoE cable (top of the Olimex).
```

A rendered/visual wiring diagram is available as an Artifact (see project chat).

---

## 7. Bill of Materials (control side)

| Qty | Part | Purpose | Have? |
|-----|---|---|---|
| 1 | Olimex ESP32-POE-ISO | Compute host + Ethernet/PoE | ✅ |
| 1 | Roboteq HDC2450 | Motor controller | ✅ |
| 1 | **MAX3232** module (w/ charge-pump caps) | ESP UART ↔ HDC2450 RS232 | ✅ bin |
| 1 | DB25 male → screw-terminal breakout | mate the HDC2450 I/O without soldering a bare DB25 | order |
| — | 802.3af PoE switch/injector | power the Olimex | ✅ likely |
| 1 | **KF0602D** DC-DC SSR (Kyotto) | remote PwrCtrl enable (§5) | ✅ |
| 1 | **S8050** NPN + 1kΩ + 10kΩ | buffers SSR input at 5V | ✅ |
| 1 | MAX485 module + XLR | optional physical DMX512 input | ✅ bin |
| 1 | E-stop switch (latching) | optional hardware E-stop | order if wanted |

**No longer on the control path:** MCP4725 DAC, MCP6002 op-amp, gain/sense resistors — the serial pivot
removed the analog stage. Keep the DAC/op-amp for another project.

---

## 8. Bring-up checklist

Do these **in order**, motor power **OFF** until step 6:

1. **MAX3232 wiring** — meter continuity: GPIO14→T1IN, T1OUT→pin3, pin2→R1IN, R1OUT→GPIO13, 3V3→VCC,
   GND→pin5. Confirm caps present on the module.
2. **Power the HDC2450 logic** (SW1 on; VBat ≥ 9V — a bench supply is fine, **motor need not be connected**).
3. **Link check** — from the ESP serial console (or a manual test), send `?FID\r`; expect the firmware
   version string back. This proves TX, RX, ground, baud, and levels all work before any motor command.
4. **Watchdog check** — confirm `^RWD 500` is accepted; stop sending `!G` and verify the controller
   reports command-loss / would stop (it will already be at 0).
5. **Telemetry check** — `?V` / `?T` return sane battery volts and temperature; note the value scaling
   and fix `SerialController::poll()` if the Roboteq units differ from the assumed ×10 (TODO in code).
6. **Motor-in-the-loop** — connect motor power; command a gentle `!G 1 100` (10%) and confirm direction,
   then `!G 1 0` stop, then `!G 1 -100` reverse. Verify slew and e-stop behave.

> The web UI's **override** slider (0=rev, 50=stop, 100=fwd) is the easy way to drive steps 6 by hand.

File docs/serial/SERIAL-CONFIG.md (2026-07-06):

# HDC2450 Serial — Config, Libraries & ESP32-over-Serial

Compiled notes for the serial track: the Roboteq ASCII protocol, the host-side
config tool, a survey of existing libraries we can borrow from, and a worked
design for **optionally adding an ESP32↔HDC2450 serial link**.

Raw research log: [`raw/`](./raw/). House rules from `CLAUDE.md` apply.

> **Scope note.** The *runtime motor command* path is and stays **analog**
> (DAC → op-amp → AnaCmd1). Serial enters the picture two ways: (1) a one-time
> **host-side config** tool to commission the controller, and (2) an *optional*
> **ESP32 serial link** for telemetry / config-assert / (maybe) command. Section
> 6 weighs that second one.

---

## 1. Roboteq ASCII protocol cheat-sheet

HDC2450 is an *Advanced Digital Motor Controller*; the whole family shares one
ASCII command set. Link is **115200 baud, 8N1, no flow control**; every command
is terminated with a carriage return (`\r`). The controller **echoes** commands
by default and replies `+` (accepted) or `-` (rejected) to writes.

| Verb | Meaning | Example | Reply |
|---|---|---|---|
| `^`  | **SetConfig** — write a config param (to RAM) | `^ACTR 1 2500` | `+` / `-` |
| `~`  | **GetConfig** — read a config param | `~ACTR 1` | `ACTR=2500` |
| `!`  | RuntimeCommand — motor/output command | `!G 1 500` | `+` / `-` |
| `?`  | RuntimeQuery — live operating value | `?A 1` | `A=...` |
| `%`  | Maintenance | `%EESAV` (save RAM→flash) | — |

Handy queries: `?FID` (firmware id, good "is anyone home?" check), `?A` (amps),
`?V` (volts: internal/battery/5V-out), `?T` (temperature), `?FF` (fault flags),
`?S`/`?BS` (speed), `?AI` (analog inputs).

Key gotchas:
- **Config is RAM-first.** `^` changes are volatile until `%EESAV`. Good — it
  lets us test and power-cycle before committing.
- **Echo on by default.** Parse tolerantly (our tool does) or disable with
  `^ECHOF 1` (itself a config param, so only if you mean to persist it).
- The HDC2450 command-loss **watchdog guards serial only, not analog** — which is
  exactly why the firmware owns the analog fail-safe (see `ARCHITECTURE.md`).

---

## 2. How the HDC2450 presents to a host

- **USB:** enumerates as a native **USB CDC-ACM** device — Linux `/dev/ttyACM*`,
  macOS `/dev/tty.usbmodem*`, **no driver install** on macOS. Not an FTDI chip.
- **RS232:** true ±RS232 levels on the DB25 (`TxOut` / `RxIn`), **not** 3.3V TTL.
  A TTL device (ESP32) needs a **MAX3232**-class level shifter to talk to it.
- **Reliability:** the forum record flags the HDC2450's **USB as EMI-sensitive
  under load** — motor/relay switching can knock the USB link offline. RS232 is
  the more robust link. Fine either way for bench commissioning; matters if we
  make a *permanent* ESP32 serial link (§6).

Refs: Roboteq forum "HDC2450 on linux with usb" (cdc_acm / ttyACM0), "HDC2450
serial communication" (115200 8N1), and the freshdesk "serial communication with
Roboteq controller and Arduino" note (RS232 levels + inversion → needs adapter).

---

## 3. Existing libraries we can borrow from

None is a drop-in for *our* design (we command via analog, and these are mostly
runtime *serial command* drivers). Value is the **serial framing + the config
command semantics** we can crib. All share the ASCII set above; only the specific
config item indices/defaults differ by controller + firmware.

| Project | Lang | Why it's useful here |
|---|---|---|
| [Miker2808/PyRoboteq](https://github.com/Miker2808/PyRoboteq) (`pip install PyRoboteq`) | Python | Clean pyserial wrapper + command table. Basis for our host tool's framing. Tested on SDC2130/SBL2360T. |
| [brettpac/Roboteq-Linux-API](https://github.com/brettpac/Roboteq-Linux-API) | C++ | Port of Roboteq's own `RoboteqDevice` (SetConfig/GetConfig/SetCommand/GetValue + `sample.cpp`). The authoritative reference for how each `^`/`~` exchange behaves. |
| [rbonghi/roboteq_control](https://github.com/rbonghi/roboteq_control) | C++/ROS | Explicitly manages *all* params, GPIO, and **analog ports** over serial; lists HDC24xx. Best reference for the config side. |
| [g/roboteq](https://github.com/g/roboteq) (`roboteq_driver`) | C++/ROS | Supports HDC24xx; example runs `/dev/ttyACM0 @ 115200` — matches our link exactly. Clean framing reference. |
| [niclaslind/arduino-roboteq](https://github.com/niclaslind/arduino-roboteq) | C++/Arduino | **PlatformIO-ready** (`lib_deps`), matches our firmware stack. Exposes `readConvertedAnalogCommand` — reads back the analog command the controller *actually sees*. Candidate base for a firmware `RoboteqLink` (§6). |

---

## 4. Config parameter map (analog mode)

The concrete param list lives in the tool's manifest:
[`tools/roto-setup/config/hdc2450-analog.json`](../../tools/roto-setup/config/hdc2450-analog.json).

Intent, grouped:

- **Command source:** `CPRI` (priority slots) so **Analog is sole authority**,
  serial left free for telemetry.
- **Analog input shaping:** `AMOD` (mode), `AINA` (action = Motor Cmd ch1),
  `AMIN`/`ACTR`/`AMAX` (mV for reverse/stop/forward), `ADB` (deadband), `APOL`.
- **Motor:** `MMOD` (open-loop), `MXMD` (mix off), `MAC`/`MDEC` (ramps),
  `MDIR` (direction).
- **Protection (set deliberately):** `ALIM` (amps), `OVL`/`UVL` (bus volts).

> Every mnemonic/value there is **DRAFT** until verified against the HDC2450
> config reference. `ACTR=2500` (2.5V stop) should equal the firmware's fail-safe
> voltage; `ADB` should be coordinated with `SafetyStage` so the two deadbands
> don't fight; `MAC`/`MDEC` should be coordinated with the persona/slew limiter so
> the *gentler* ramp governs ultra-slow modes.

---

## 5. Host-side config tool

[`tools/roto-setup/`](../../tools/roto-setup/) — pyserial, config-only, dry-run by
default, verify-on-write, RAM-until-`--save`. See its
[README](../../tools/roto-setup/README.md). This replaces the need to boot RoboRun+
in a Windows VM just to flip the controller into analog mode.

---

## 6. Design: should the ESP32 also talk serial to the HDC2450?

Today the ESP32 only drives the controller through the analog chain. Adding a
serial link is worth reasoning about because it closes two gaps the current design
*names but can't fill from the analog side*: **no controller-side telemetry**
(real amps/temp/faults) and **no controller-side command-loss watchdog**.

### Hardware cost (common to all options)

The DB25 serial port is **RS232**, the ESP32 is **3.3V TTL** → we need a
**MAX3232** (or equiv) level shifter. Two ESP32 GPIOs for UART TX/RX. Reuse the
existing **single-point ground** (DB25 pin 5, already our analog reference) for
the serial ground — no new ground path.

**Pin constraint (hard):** RMII Ethernet owns GPIO 0,12,18,19,21,22,23,25,26,27 —
never reuse. Already spoken for: 35 (DMX RX), 36 (sense ADC), 39 (E-stop),
32 (PwrCtrl), 13/16 (I2C, to confirm). Candidate UART pins **to verify against the
Olimex ESP32-POE-ISO Rev M schematic**: **TX = GPIO33**, **RX = GPIO34** (34 is
input-only, fine for RX; TX must be a full output). Confirm before soldering.

### Options

**Option A — Analog command + serial telemetry/config-assert  *(recommended)***
Keep the locked analog command path. Add serial as a **read-only telemetry** feed
(`?A ?V ?T ?FF ?S`) and an optional **boot-time config-assert** (re-push the
analog-mode config + protection limits over `^`, so a controller that got reset or
mis-flashed comes back known-good without RoboRun+).
- *Pros:* purely additive; doesn't re-open the locked analog decision; serial is
  **not** in the motor-command critical path, so USB/EMI flakiness can't stop the
  motor; directly fills the telemetry gap the `Telemetry`/`Diagnostics` modules
  already pencil in (`ARCHITECTURE.md` Phase 2/5).
- *Cons:* still no controller-side command-loss watchdog (analog command remains
  watchdog-less — firmware fail-safe still mandatory); adds the MAX3232 + 2 pins.

**Option B — Serial *command* (replace the analog chain)**
Drop MCP4725 + op-amp; command with `!G 1 x` (±1000).
- *Pros:* simpler BOM (no DAC, no op-amp gain math, no ratiometric-5V dance);
  digital precision (finer than 12-bit DAC) — nice for ultra-slow; **built-in
  RS232 watchdog** (`RWD`) gives the controller-side command-loss stop the analog
  path lacks.
- *Cons:* **re-opens a locked decision**; serial-under-load reliability risk
  (mitigated by RS232 vs USB, but real); loses the dead-simple isolated single
  analog line; you must *stream* commands within the watchdog window (that's the
  fail-safe working as intended, but it's a behavioral shift); more firmware in
  the motion-critical path.

**Option C — Serial config-only, from the ESP32**
ESP32 does the one-time/occasional config over serial instead of the host tool.
- *Pros:* fewest moving parts *if* you don't want a host laptop at the controller.
- *Cons:* still needs the MAX3232 + pins for a job the host tool already does over
  USB with no added hardware. Low value unless there's a field re-config need.

### Recommendation

**Option A.** It's additive, respects the locked analog command path and the
paper-validated safety story, and it's the highest-value / lowest-risk way to get
real controller telemetry and self-healing config. It also leaves the physical
link in place, so a later A/B of **B** (serial command) is a firmware change, not
a hardware change. If bench testing later shows the analog watchdog gap is
unacceptable, revisit **B** deliberately (it would be a real decision, logged in
`CLAUDE.md`, not a drift).

### Firmware sketch (if we do A)

A `RoboteqLink` module mirroring the existing module style, feeding the existing
`Telemetry` module rather than the command path:

```
UART2 (TX33/RX34) ──MAX3232── DB25 RS232 (TxOut/RxIn, GND=pin5)
        │
   RoboteqLink
     ├─ begin(uart, baud=115200)
     ├─ assertConfig(manifest)   // optional, boot-time ^ + verify (mirrors roto_setup.py)
     ├─ poll()                   // periodic ?A ?V ?T ?FF ?S -> struct
     └─ Telemetry <- {battV, amps, tempC, faultFlags, rpm}
```

- **Read-only by default.** No `!` commands in Option A — the analog chain still
  commands the motor, so a serial glitch degrades telemetry, never motion.
- `readConvertedAnalogCommand` (from the arduino-roboteq lib) is a great
  cross-check: compare what the controller *thinks* its analog command is against
  our `SenseADC` measurement of the op-amp output — a cheap integrity check on the
  whole analog chain.
- Poll slowly (e.g. 5–10 Hz); keep the UART off the RMII pins; share the
  single-point ground.

---

## 7. Open questions / TODO

- [ ] Verify all §4 mnemonics/values against the HDC2450 config reference.
- [ ] Nail down the `AINA` action bitmask encoding (Motor Cmd, ch1).
- [ ] Fill `ALIM`, `OVL`, `UVL` from the actual motor + bus specs.
- [ ] Confirm `%EESAV` needs no safety argument on this firmware rev.
- [ ] Confirm **TX33/RX34** free on the Olimex POE-ISO **Rev M** schematic.
- [ ] Decide A vs B vs C. (Leaning A — telemetry + config-assert, analog stays.)
- [ ] If A: pick a MAX3232 breakout; add serial port to the DB25 hood pinout in
      `HARDWARE.md`.
- [ ] Once decided, add `RoboteqLink` to the `ARCHITECTURE.md` module map and fold
      Phase-2 telemetry into the roadmap explicitly.

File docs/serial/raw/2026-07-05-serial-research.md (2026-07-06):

# raw — serial research log — 2026-07-05

Running notes; unpolished on purpose. Compiled version → `../SERIAL-CONFIG.md`.

## Trigger
Wanted RoboRun+ on macOS to set up the HDC2450. RoboRun+ is Windows-only
(`RoborunPlus.exe`), talks to controller over a virtual COM port (USB/RS232/TCP).
Realized the GUI is the easy part — the hard part is getting the controller's
serial port to whatever runs it. And then: maybe we don't need the GUI at all.

## HDC2450 USB identity (important)
- Enumerates as **USB CDC-ACM**, NOT FTDI. Linux `dmesg`: `cdc_acm ... ttyACM0`.
  → macOS = `/dev/tty.usbmodem*`, **no driver needed**.
- Serial params: **115200 8N1 no flow**. 3 wires for RS232 (Rx/Tx/GND).
- Forum lore: USB link is **EMI-sensitive** — "firing off a relay pulls the USB
  offline"; USB described as "not robust." RS232 more reliable under load.
- Can't use CAN + USB simultaneously; CAN + RS232 is OK.
- src: roboteq forum threads (hdc2450 on linux with usb; hdc2450 serial
  communication; unable to establish connection with USB in HDC2450).

## Protocol verbs (ADMC family — HDC2450 is one)
- `^` SetConfig (RAM), `~` GetConfig, `!` runtime cmd, `?` runtime query,
  `%` maintenance. `%EESAV` = save RAM→flash. `?FID` = firmware id.
- Echo ON by default; `^ECHOF 1` disables. Replies `+`/`-`.
- Watchdog (`RWD`) guards SERIAL only. Analog holds last voltage → our firmware
  must own the fail-safe. (Already in ARCHITECTURE.md safety model.)

## Running RoboRun+ on mac — options considered
1. **VM + USB passthrough** (UTM free / Parallels smooth / VMware Fusion free).
   Most reliable: raw USB device → Windows loads CDC driver → COM port → RoboRun+
   auto-scans. Win11 ARM emulates the x86 exe fine.
2. **Wine/Whisky/CrossOver** — launches GUI but CDC→COM bridging is fiddly &
   unreliable. Skip for writing config to hardware.
3. **Skip Windows entirely** — controller is already `/dev/tty.usbmodem*`, speaks
   ASCII. Send `^`/`~` from pyserial. ← chose this. Became `tools/roto-setup/`.
   RoboRun+ only truly needed for firmware update / config-tree GUI / live charts
   / MicroBasic. None of which our analog bridge needs.

## Library survey (see compiled doc for links)
- PyRoboteq (pip) — pyserial wrapper, tested SDC2130/SBL2360T. Good framing base.
- brettpac/Roboteq-Linux-API — vendor RoboteqDevice port, SetConfig/GetConfig +
  sample.cpp = authoritative config semantics.
- rbonghi/roboteq_control (ROS) — controls ALL params incl analog ports; HDC24xx.
- g/roboteq roboteq_driver (ROS) — HDC24xx, ttyACM0@115200 (matches us).
- niclaslind/arduino-roboteq — PlatformIO lib_deps; has readConvertedAnalogCommand
  (read back the analog cmd the controller sees — nice chain integrity check).
- kippandrew/Arduino-RobotEQ, Azrrael-exe/Ard-Roboteq (AX2550) — simpler arduino.
- Caveat across all: command SET is shared, but config item indices/defaults vary
  by controller+firmware. Borrow framing, verify the numbers.

## Tool decisions (roto_setup.py)
- Config-only, never `!`. Dry-run default. Verify every write via read-back.
- RAM until `--save` (%EESAV). `--audit` read-only. Placeholder (null/TODO) values
  SKIPPED so we can't flash a stub. Manifest-driven (JSON), values are DATA.
- Echo-tolerant line parser (works echo on/off), FID as connection check.
- Smoke-tested framing/diff/verify with a fake controller. Real-hardware TODO.

## ESP32-over-serial — thinking (→ compiled §6)
Idea: ESP32 also speaks serial to HDC2450. Closes 2 named gaps: no controller
telemetry, no analog command-loss watchdog.
- HW cost: DB25 is RS232 not TTL → need **MAX3232**. 2 GPIOs. Reuse pin-5 GND.
- Pins: RMII owns 0/12/18/19/21/22/23/25/26/27. Taken: 35,36,39,32,13,16.
  Candidate TX=33 RX=34(input-only ok). VERIFY on POE-ISO Rev M schematic.
- **A (recommended):** analog command stays; serial = read-only telemetry +
  optional boot config-assert. Additive, off the motion-critical path, fills the
  telemetry gap already in the roadmap.
- **B:** serial command replaces analog. Simpler BOM, digital precision, gets the
  RS232 watchdog — BUT re-opens locked decision + reliability risk + streaming
  requirement. Only via a deliberate logged decision.
- **C:** serial config-only from ESP32. Low value vs the host tool (which needs no
  extra HW). Only if there's a field re-config need.
- Firmware: `RoboteqLink` module → feeds existing `Telemetry`. Poll 5–10Hz.
  Cross-check readConvertedAnalogCommand vs SenseADC = analog-chain integrity test.

## Next actions
- Verify mnemonics/values vs HDC2450 reference; fill ALIM/OVL/UVL; AINA bitmask.
- Confirm %EESAV arg-less on this rev.
- Decide A/B/C (leaning A). If A: pick MAX3232 breakout, add serial to DB25 hood
  pinout in HARDWARE.md, add RoboteqLink to ARCHITECTURE.md module map.
- Run roto_setup.py --audit against the real controller (motor power OFF).

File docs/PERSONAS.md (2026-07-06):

# DMX Personas & Speed Scaling

How incoming DMX/Art-Net/sACN values map to the HDC2450 motor command. Personas select a **command
range** (coarse behaviour + ultra-slow modes); a live **web multiplier** trims within that range.

The firmware works in a **normalized command `c ∈ [-1, 1]`** (0 = stop, +1 = full forward, −1 = full
reverse). `SerialController` scales that to the HDC2450's `!G` range: `g = round(c × 1000)`.

---

## Concept

The HDC2450 speed is proportional to the command value. Two levers:

1. **Persona** — picks the command window the full DMX range maps onto. A *narrower* window = lower top
   speed but the **same DMX resolution spread over a smaller speed band** → finer, slower control
   ("ultra-slow mode").
2. **Multiplier** (web UI, 0.00–1.00, live) — scales the mapped output within the persona window.

Serial gives effectively continuous resolution — `!G` spans −1000..+1000 (2000 steps) and the
controller's internal loop is finer still — so even a narrow ultra-slow window stays smooth (no DAC
quantization to worry about; this is a win over the retired analog path).

| Persona window | Command range | Feel |
|---|---|---|
| Full | 0 → ±1000 | Full speed |
| Half (slow) | 0 → ±500 | Half top speed, fine |
| Quarter (ultra-slow) | 0 → ±250 | Crawl, very fine |

---

## Direction models

- **Bidirectional** (default): DMX center = stop; below center = one direction, above = the other;
  speed grows toward the extremes. `c ∈ [-1, 1]`.
- **Unidirectional**: forward only, `c ∈ [0, 1]` (DMX 0 = stop).

Firmware persona flag picks the math; no Roborun+ reconfig needed.

---

## Persona definitions (v1)

`c` = normalized command in [-1,1]. `m` = web multiplier (0–1). `d` = DMX normalized to 0.0–1.0
(8-bit: `dmx/255`; 16-bit: `(coarse*256+fine)/65535`).

### P1 — Full · Unidirectional (1 ch, 8-bit)
```
c = d * m               # 0 (stop) → +1 (full fwd)
```
One DMX channel. Stop at DMX 0. (Use when the roto only ever spins one way.)

### P2 — Full · Unidirectional · 16-bit (2 ch)
```
c = d16 * m             # coarse+fine channels for buttery ramps
```

### P3 — Ultra-Slow ½ · Unidirectional (1 ch, 8-bit)
```
c = d * m * 0.5         # 0 → +0.5
```

### P4 — Ultra-Slow ¼ · Unidirectional (1 ch, 8-bit)
```
c = d * m * 0.25        # 0 → +0.25
```

### P5 — Full · Bidirectional (1 ch, 8-bit) — **default persona**
```
b = deadband((d - 0.5) * 2)   # -1..+1, center at DMX 128
c = b * m                     # -1 (full rev) .. 0 (stop) .. +1 (full fwd)
```
Continuous deadband around DMX 128 (configurable ± counts) guarantees a true stop at center.

### P6 — Ultra-Slow · Bidirectional (1 ch, 8-bit)
```
c = deadband((d - 0.5) * 2) * m * 0.25    # +/-25% either direction, fine
```

### P7 — Full · Bidirectional · 16-bit (2 ch)
16-bit version of P5 for smooth reversible slow motion.

> All personas clamp `c` to the valid range. `SerialController` maps `c → !G g` (±1000).

---

## Global parameters (web UI, persisted)

| Param | Range | Effect |
|---|---|---|
| `persona` | P1–P7 | Active mapping (default P5) |
| `dmxStart` | 1–512 | Start address (footprint = 1 or 2 ch) |
| `multiplier` | 0.00–1.00 | Live output scale within persona window |
| `deadband` | 0–40 DMX counts | Stop zone around center (bidirectional) |
| `slewLimit` | command units/s | Max rate-of-change on `c` (protects mechanics); 0 = off |
| `invert` | bool | Flip direction sense |

The **fail-safe command is always 0 (stop)** — no separate parameter. On boot, link-loss, source-stale,
or e-stop, `SafetyStage` slews the command to 0, and the HDC2450's `^RWD` watchdog independently stops
the motor if our command stream dies.

**Slew limiting** is applied after persona math, before the command is sent — a snapped DMX jump can't
slam the motor.

---

## Manual override (web UI)

A master **OVERRIDE** toggle takes control away from DMX/Art-Net/sACN and exposes a direct slider
(0 = full reverse, 50 = stop, 100 = full forward, fed through the active persona). While engaged:
- Incoming network/DMX values are ignored (still displayed for reference).
- The same `slewLimit` and clamps apply.
- A visible banner marks the override state.

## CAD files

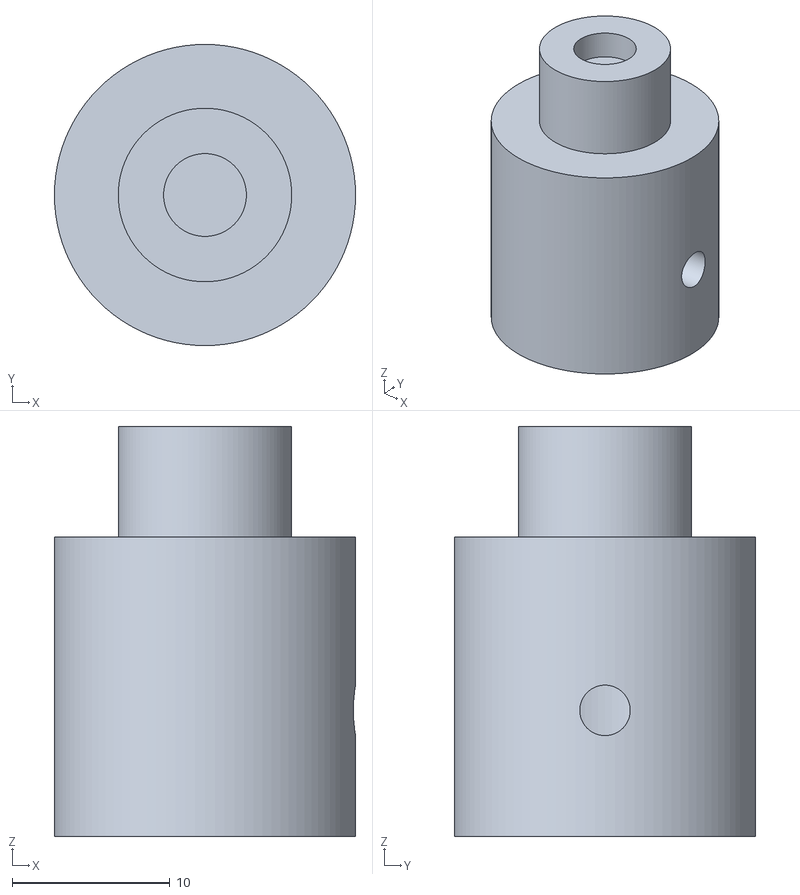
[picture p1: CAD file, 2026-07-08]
tools/as5600-reader/stl/as5600_carrier.stl
19.1 x 19.1 x 26.0

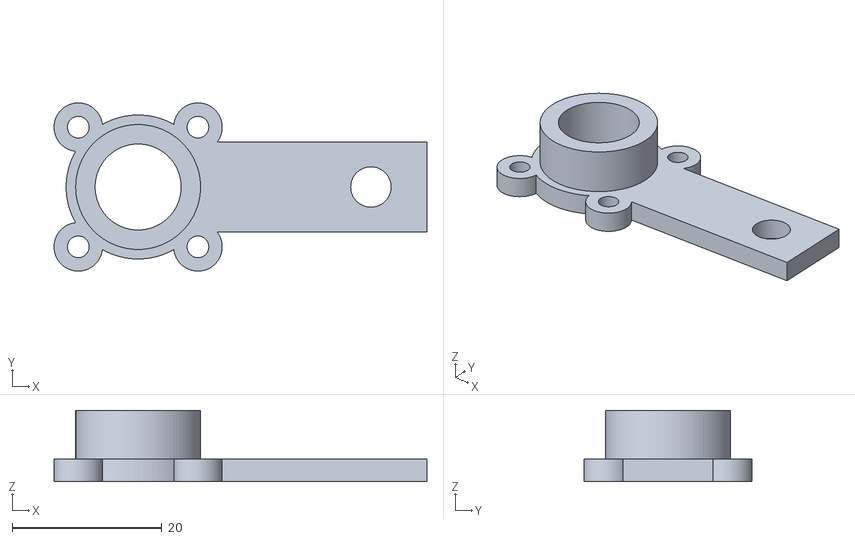
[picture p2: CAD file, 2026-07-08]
tools/as5600-reader/stl/as5600_holder.stl
49.9 x 22.5 x 9.50

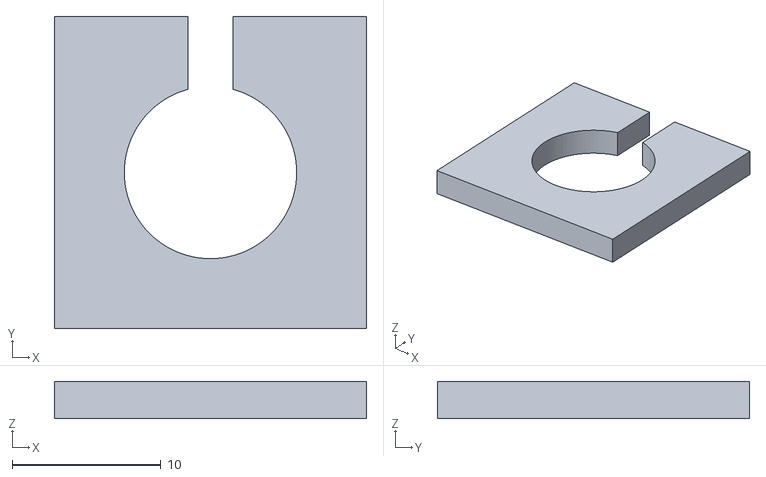
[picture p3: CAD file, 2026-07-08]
tools/as5600-reader/stl/as5600_gauge.stl
21.0 x 21.0 x 2.50

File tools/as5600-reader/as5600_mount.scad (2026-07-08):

// as5600_mount.scad — AS5600 encoder mount for the roto shaft. NESTED / self-spacing design.
//
// The two printed parts SET THE GAP BY NESTING TOGETHER — no external reference:
//   - MAGNET CARRIER grips the shaft, holds the 5x2 diametric magnet on-axis on a raised PILOT,
//     and has a SHOULDER (the step where the pilot meets the wider body).
//   - SENSOR HOLDER cups over the pilot (bore = running clearance) and its hub bottom SEATS ON the
//     shoulder. That seat is the spacer: it fixes the board exactly `air_gap` above the magnet.
//     The carrier spins under it; they rub at the seat (slow roto -> fine; a thrust washer/bearing
//     can drop onto the pilot later). The board rides on the holder because the holder rides the
//     carrier, so the gap stays constant even if the shaft wobbles.
//
// The L-BRACKET only stops the holder from spinning (anti-rotation ear) — use any spare bracket.
//
// Frame: shaft axis = Z; magnet TOP face = z 0; carrier shoulder = z -pilot_h; board face = z air_gap.

part = "assembly";        // "carrier" | "holder" | "gauge" | "assembly"

/* ---------- the gap (set by the nested seat) ---------- */
air_gap       = 2.5;      // magnet top -> board chip-side face. Chip body pokes ~1.5mm in -> die ~1.3mm off.

/* ---------- shaft (rotating) ---------- */
shaft_d       = 12.7;     // [MEASURE] 1/2" tip
shaft_engage  = 16;
bore_floor    = 3.0;      // SOLID floor above the shaft bore that ties the pilot to the body
                          //   (the bore is wider than the pilot, so this connection is required)
shaft_fit     = 0.45;     // ABS-friendly bore clearance (tune to your printer)
wall          = 3.2;
set_screw_d   = 3.2;      // M3 grub
set_screw_z   = 8;

/* ---------- magnet (5 x 2 DIAMETRIC) ---------- */
magnet_d      = 5.0;
magnet_th     = 2.0;
magnet_fit    = 0.25;     // ABS-friendly pocket clearance
magnet_recess = 0.3;

/* ---------- register pilot + shoulder (the spacer interface) ---------- */
pilot_d       = 11.0;     // pilot the holder cups over (> magnet, gives a clean register)
pilot_h       = 7.0;      // pilot height above the shoulder (magnet pocket + register length)
hub_fit       = 0.25;     // radial running clearance holder bore over pilot. TIGHT on purpose: this
                          //   register centers the chip over the magnet (both parts printed, so ABS
                          //   shrinkage cancels). ~0.5mm total slop -> spins yet stays concentric.
                          //   If it binds, sand the pilot lightly or bump to 0.3.
hub_wall      = 2.6;      // holder hub wall

/* ---------- AS5600 board (23 x 23, chip centered, holes 16mm c-c, 3.5mm) ---------- */
board_sz      = 23.0;
board_th      = 1.6;
board_hole_sp = 16.0;     // corner mounting-hole spacing
board_hole_d  = 3.5;
boss_screw_d  = 2.9;      // self-tap M3 into the board bosses

/* ---------- anti-rotation ear (to a spare L-bracket) ---------- */
ear_len       = 26;
ear_w         = 12;
ear_th        = 5;
ear_hole_d    = 5.4;      // M5 clearance

eps = 0.02;  $fn = 96;
carrier_od = shaft_d + 2*wall;
body_h     = shaft_engage + bore_floor;    // body = shaft grip + solid floor under the pilot
carrier_h  = body_h + pilot_h;             // native total
hub_bore   = pilot_d + 2*hub_fit;
hub_od     = pilot_d + 2*hub_fit + 2*hub_wall;
hs         = board_hole_sp/2;
plate_d    = board_sz*sqrt(2)*0.5 + 3;     // disc big enough to reach the corner bosses
plate_th   = 3.0;

// ================= MAGNET CARRIER (native: base z 0, pilot up) ================= //
module magnet_carrier() {
  difference() {
    union() {
      cylinder(d = carrier_od, h = body_h);                       // body (shoulder = top face)
      translate([0,0,body_h]) cylinder(d = pilot_d, h = pilot_h); // register pilot
    }
    translate([0,0,-eps]) cylinder(d = shaft_d + shaft_fit, h = shaft_engage + eps);         // shaft bore
    translate([0,0, carrier_h - magnet_th - magnet_recess])
      cylinder(d = magnet_d + magnet_fit, h = magnet_th + magnet_recess + eps);              // magnet pocket
    translate([0,0,set_screw_z]) rotate([0,90,0]) cylinder(d = set_screw_d, h = carrier_od/2 + eps); // set screw
  }
}

// ================= SENSOR HOLDER (assembly coords: seats at z -pilot_h) ================= //
module sensor_holder() {
  hub_bot = -pilot_h;                       // hub bottom rests on the carrier shoulder
  plate_bot = air_gap - plate_th;
  // hub tube (open bore so the chip sees the magnet)
  translate([0,0,hub_bot]) difference() {
    cylinder(d = hub_od, h = plate_bot - hub_bot + eps);
    translate([0,0,-eps]) cylinder(d = hub_bore, h = plate_bot - hub_bot + 3*eps);
  }
  // board plate: disc + central window + 4 corner bosses (board sits chip-down at z air_gap)
  difference() {
    union() {
      translate([0,0,plate_bot]) cylinder(d = plate_d, h = plate_th);
      for (dx=[-1,1], dy=[-1,1]) translate([dx*hs, dy*hs, plate_bot]) cylinder(d = 6.5, h = plate_th);
    }
    translate([0,0,plate_bot-eps]) cylinder(d = hub_bore, h = plate_th + 2*eps);             // chip window
    for (dx=[-1,1], dy=[-1,1]) translate([dx*hs, dy*hs, air_gap-4]) cylinder(d = boss_screw_d, h = 4+eps); // board screws
  }
  // anti-rotation ear out to a spare L-bracket (retention only, NOT the gap)
  difference() {
    hull() {
      translate([plate_d/2-2, -ear_w/2, plate_bot]) cube([eps, ear_w, plate_th]);
      translate([plate_d/2-2+ear_len, -ear_w/2, plate_bot]) cube([ear_th, ear_w, plate_th]);
    }
    translate([plate_d/2-2+ear_len-ear_th/2, 0, plate_bot-eps]) cylinder(d = ear_hole_d, h = plate_th + 2*eps);
  }
}

module gap_gauge() {  // shim to confirm the seated gap
  gw = pilot_d + 10;
  difference() {
    translate([-gw/2,-gw/2,0]) cube([gw, gw, air_gap]);
    translate([0,0,-eps]) cylinder(d = pilot_d + 0.6, h = air_gap + 2*eps);
    translate([-1.5,0,-eps]) cube([3, gw, air_gap + 2*eps]);
  }
}

// ---- preview ghosts ----
module ghost_magnet() { color("red")   translate([0,0,-magnet_th]) cylinder(d=magnet_d, h=magnet_th); }
module ghost_shaft()  { color("silver")translate([0,0,-carrier_h-20]) cylinder(d=shaft_d, h=carrier_h+20); }
module ghost_board()  { color("green") translate([-board_sz/2,-board_sz/2, air_gap]) cube([board_sz,board_sz,board_th]); }

if (part == "carrier")      magnet_carrier();                              // print: shaft-bore down, pilot up
else if (part == "holder")  rotate([180,0,0]) translate([0,0,-air_gap]) sensor_holder();  // print: board-plate flat down, hub up
else if (part == "gauge")   gap_gauge();                                   // print: flat
else {
  translate([0,0,-carrier_h]) magnet_carrier();   // magnet top -> z 0
  ghost_magnet(); %ghost_shaft(); %ghost_board();
  sensor_holder();
}

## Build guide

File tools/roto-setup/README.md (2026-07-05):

# roto-setup — HDC2450 serial config tool

Host-side (macOS/Linux) utility that commissions the **Roboteq HDC2450** into
**analog-command mode** for RA Roto Control, over USB or RS232 serial. It reads,
writes, and **verifies** configuration using the Roboteq ASCII protocol.

It is **config-only** — it never sends a motor command. The values it writes come
from a JSON manifest (`config/hdc2450-analog.json`), so the exact parameters are
data you can review and version, not code.

> Full protocol notes, the library survey this was built from, and the
> ESP32-over-serial design discussion live in [`docs/serial/SERIAL-CONFIG.md`](../../docs/serial/SERIAL-CONFIG.md).

## Why a serial tool if we command over analog?

The **runtime** command path is analog (DAC → op-amp → AnaCmd1) and stays that
way. But the controller still has to be *told* to listen to its analog input and
how to scale it — that's a one-time configuration, normally done in RoboRun+
(Windows). This tool does the same job from the Mac, scriptably and repeatably,
and reads every value back so you catch mistakes on the bench instead of in the
field.

## Install

```bash
pip install pyserial        # only dependency
```

The HDC2450's USB shows up on macOS as `/dev/tty.usbmodem*` with **no driver**
(it's a USB CDC-ACM device). A USB↔RS232 adapter into the DB25 serial pins shows
up as `/dev/tty.usbserial*`. Either works; the tool auto-detects.

## Safety model

| Flag | What it does | Writes? | Persists? |
|---|---|:---:|:---:|
| `--audit` | Read-only dump of the manifest keys | no | no |
| *(none)* | **Dry-run**: show current → target diff | no | no |
| `--apply` | Write to RAM, then read back & verify each | RAM | no |
| `--apply --save` | As above, then `%EESAV` to flash | RAM | **flash** |

- **Dry-run is the default.** You have to opt in to writing.
- **Every write is verified** by an immediate read-back.
- **Nothing persists** to the controller's flash until you explicitly `--save`,
  so you can write, power-cycle, confirm your fail-safe, and only then commit.
- Manifest items with a `null`/`"TODO"` value are **skipped** — a placeholder can
  never be flashed by accident. (Currently: `AINA`, `ALIM`, `OVL`, `UVL`.)

## Quickstart

```bash
cd tools/roto-setup

# 1. See what's currently on the controller (read-only)
./roto_setup.py --audit

# 2. See what WOULD change (no writes)
./roto_setup.py

# 3. Write to RAM and verify (still not persisted)
./roto_setup.py --apply

# 4. Power-cycle, re-audit, confirm fail-safe. Then commit to flash:
./roto_setup.py --apply --save
```

Pin the port or manifest if needed:

```bash
./roto_setup.py --port /dev/tty.usbmodem1101 --manifest config/hdc2450-analog.json --debug
```

## Before you run it

1. **MOTOR POWER OFF.** This writes config, not motion — but bench-validate with
   the motor stage disconnected, per the project's hardware-first rule.
2. **Fill in the deliberate blanks** in the manifest: `ALIM` (amps limit),
   `OVL`/`UVL` (bus voltage limits), and the `AINA` action bitmask. These have no
   safe defaults, so they're left `null` on purpose.
3. **Treat every mnemonic/value as DRAFT** until you've checked it against the
   HDC2450 config reference (RoboRun+ Configuration tab, or the Advanced Digital
   Motor Controllers user manual). The tool's job is to make a wrong value
   *visible and reversible*, not to guarantee the value is right.

## Exit codes

- `0` — success (audit done / dry-run done / applied & verified / saved)
- `1` — a verify failed, save failed, or a fatal serial/manifest error

## Caveats

- Some config params read back in a normalized form (e.g. you write a percent,
  the controller returns raw counts). A verify "failure" can be legitimate
  scaling — the tool surfaces the mismatch for you to judge rather than hiding it.
- The HDC2450's **USB** is EMI-sensitive under load (motor/relay switching can
  knock it offline). For commissioning that's fine; if you ever want a permanent
  ESP32↔controller serial link, use the **RS232** pins on the DB25 (more robust)
  via a MAX3232 — see the design doc.

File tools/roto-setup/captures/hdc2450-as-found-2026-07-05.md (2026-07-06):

# HDC2450 — As-Found Configuration Catalog

> **Captured 2026-07-05** via `roto_setup.py --audit` (read-only, no writes) over USB
> `/dev/cu.usbmodemRTQ00101` @ 115200 8N1. Raw dump: `hdc2450-as-found-2026-07-05.txt`.
> This is the **backup of the existing config before any change.** Values below are read
> verbatim; the "meaning" column is interpretation (verify unit/enum against the Roboteq
> ADMC config-command reference before relying on it).

## Command priority (CPRI) — FACTORY DEFAULT

| Slot | Value | Meaning |
|---|---|---|
| CPRI 1 | 0 | Serial/USB (highest) |
| CPRI 2 | 1 | RC pulse |
| CPRI 3 | 2 | **Analog (lowest)** |

→ Matches the datasheet default "1-RS232, 2-RC, 3-Analog." **Analog is the lowest-priority
command.** Any serial `!G` or RC signal overrides the analog command. Relevant later: the
future serial-command path can take over *without* a config change, because serial outranks analog.

## Globals / protection

| Key | Value | Meaning |
|-----|---|---|
| RWD | 1000 | serial command-loss watchdog = **1000 ms** (guards serial only, not analog) |
| ECHOF | 0 | serial echo ON |
| PWMF | 180 | PWM ≈ 18.0 kHz |
| OVL | 450 | over-voltage cutoff ≈ **45.0 V** |
| UVL | 50 | under-voltage cutoff ≈ **5.0 V** |
| MXMD | 0:0 | mixing OFF (independent channels) |
| BRUN | 0 | no auto-start MicroBasic script |

## Analog inputs (as-found)

| Input | Pin | Decode8 out | AMOD | AINA | AMIN | ACTR | AMAX | ADB | Role (interpreted) |
|---|-----|---|---|---|---|---|---|-----|---|
| ANA1 | 15 | out 2 | 0 | **16** | 250 | 2500 | 4750 | 5 | non-command (no channel bit) |
| ANA2 | 16 | out 3 | 0 | **48** | 250 | 2500 | 4750 | 5 | non-command (no channel bit) |
| ANA3 | 4  | out 4 | 0 | **33** | 100 | 1270 | 2500 | 0 | **Motor 1 command** — this is the DEAD pin |
| ANA4 | 17 | out 5 | 1 | **33** | 100 | 1275 | 2400 | 0 | **Motor 1 command** — the WORKING input |
| ANA5 | 21 | — | 0 | 0 | — | — | — | — | unused (unwired) |
| ANA6 | 22 | — | 0 | 0 | — | — | — | — | unused (unwired) |

**AINA decode (interpreted — verify against manual):** low bit = motor-channel mask.
`33 = 0x21` → bit0 set → **Motor Channel 1 command**. `16`/`48` have no channel bit → not
motor commands (some monitor/feedback action). So **both ANA3 (pin 4) and ANA4 (pin 17) are
assigned to command Motor 1**; ANA1/ANA2 are not motor commands.

**Calibration note:** ANA3/ANA4 use a compressed window — center ≈ **1.27 V** (stop), max ≈
**2.4 V** (full forward), min 100 mV (full reverse). The Decode8 outputs 0–5 V, so with this
calibration: DMX 0 → full reverse, DMX ≈25 % → stop, DMX ≈47 %+ → pinned full forward. Control
lives in the lower ~half of the DMX range. (ANA1/ANA2 use a wider 250/2500/4750 mV window.)

## Motor channels

| Key | M1 | M2 | Meaning |
|-----|----|----|---|
| MMOD | 0 | 0 | open-loop (no encoder) |
| MAC | 500 | 20000 | acceleration ramp |
| MDEC | 500 | 20000 | deceleration ramp |
| MXPF | 100 | 50 | max power forward (M1 full, M2 half) |
| MXPR | 100 | 50 | max power reverse |
| MXRPM | 1000 | 1000 | max RPM reference (open-loop scaling) |
| ALIM | 1000 | 1000 | amps limit ≈ **100.0 A** per channel |
| ATGA | 16 | 0 | amps-trigger action (M1 set, M2 none) |

→ **Motor 1 is the commissioned motor** (full power, both wired analog inputs target it). Motor 2
is secondary (half power). Strongly implies the physical motor is on the **M1** output.

---

## What this means for the plan (no changes made yet)

1. **ANA4 (pin 17, the working input) is already a Motor 1 command.** So DMX5 → ANA4 → **Motor 1**
   should already drive the motor — your "just use analog 4" idea is essentially already wired in
   config. No remap needed to command Motor 1 from ANA4.
2. **ANA3 (pin 4, the dead/floating pin) is ALSO a Motor 1 command.** That is a hazard: a floating
   input assigned to the motor can fight ANA4 for control. The one clean change to make (later,
   deliberately) is **`AINA 3 = 0`** to remove the dead pin's authority over Motor 1.
3. **Analog is lowest command priority** — fine now (nothing sends serial/RC), and convenient for
   the future serial takeover.
4. Protection is real (100 A limit, 45 V OV, 5 V UV) — do not treat this as a blank controller.

**Proposed single change when ready:** `^AINA 3 0` (RAM only, verify, power-cycle test) so the
working ANA4 is the sole Motor-1 analog command. Everything else can stay as-found for a first
motor-in-the-loop test.

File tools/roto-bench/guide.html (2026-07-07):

# RA Roto — Operator Guide

Control console for the Roboteq HDC2450 motor controller. Read the safety section before driving a motor.

1 · What this is 2 · Quick start 3 · Safety model 4 · Run modes 5 · Settings & limits 6 · Tools 7 · Tuning a loaded roto 8 · Reading the telemetry 9 · Troubleshooting

## 1 · What this is

The full system bridges show-control protocols (DMX512, Art-Net, sACN) to a rotating fixture: DMX/Art-Net/sACN → ESP32-POE-ISO → RS232 serial (!G) → Roboteq HDC2450 → motor. Everything drives the motor over serial — one signed command sets speed and direction, the controller's own watchdog self-stops on comms loss, and it streams back real telemetry. No DAC, op-amp, or calibration.

This console is the host-side control surface that drives that serial link today, over USB — for bench bring-up, tuning, and running a self-contained piece. The ESP32 firmware (a follow-up, pending parts) will be the networked front-end feeding the same serial path.

## 2 · Quick start

1. Power the motor from a supply that can deliver the current you need. During first bring-up, a current-limited PSU (e.g. 5 A) is a physical safety net.
2. Keep the controller's hardware E-STOP reachable.
3. Pick a run mode → press ARM → drive. Stop = release the slider (JOG), press Zero, or E-STOP.

The console starts DISARMED and always logs to logs/. Nothing moves until you ARM.

## 3 · Safety model

Protection is layered — fastest/most-local first. A fault stops the motor, it doesn't run it.

Layer | What it does
PSU current limit | Physical, reset-proof. The real ceiling on energy for bring-up.
ALIM foldback | Controller caps motor current at the set limit.
^RWD watchdog | The console streams !G continuously; if it dies, the controller self-stops in ~0.5 s.
Overtorque backoff | When pinned at the current limit, gently ramps the command down to relieve torque — so a jam can't wind up and break free violently. (See below.)
Stall / overcurrent trip | Amps held near the limit too long → stop + disarm. RUN modes only.
Temperature trip | Controller heatsink temp too high → stop. Note: this is the controller, not the motor.
I²t trip | Leaky current²·time estimate of motor heating → stop. Our only motor-winding thermal proxy.
Control-drift alarm | Watches ALIM/RWD/AINA vs an expected baseline; alarms if a controller reset reverts them. One-click Re-apply safe profile.
Operator layer | Arm gate, hold-to-run, browser deadman, command cap + slew, E-STOP.

On any trip: command → 0, motor disarmed, latched until you clear it. A red banner, an audible alarm, and a timestamped alert appear. The command card also shows why output is held at 0 (DISARMED / DEADMAN / TRIPPED / E-STOP) — so "armed but not moving" is never a mystery.

Jam vs. hold: open-loop (no encoder) can't tell a jam from a loaded hold by current alone. That's why RUN modes stall-trip on current while HOLD/CREEP rely on temperature + I²t. An encoder (closed loop) is the real fix.

## 4 · Run modes

Mode | Behaviour | Use for
JOG | Hold the slider to run; release = stop. Deadman-protected. | Setup, positioning, testing.
CRUISE | Set a speed; it holds. Stall-protected. | Steady running.
DRIFT | Auto slow sweep around a center point (amplitude · center · period · waveform). | Ambient / atmospheric motion.
HOLD | Maintain position under load; stall-trip off, temp/I²t still guard. | Holding against a load.
CREEP | Very slow under load; stall-trip off, anti-stiction kick on start. | Slow loaded creep.

### DRIFT patterns

command = center + amplitude · wave(t). center biases the sweep (0 = balanced fwd/rev; +300 = mostly-forward breathing). waveform: sine (smooth), triangle (linear), saw (ramp+snap). Keep the speed cap ≥ |center| + amplitude or the peaks clip.

## 5 · Settings & limits

### Host-side (console)

Speed cap | Ceiling on command magnitude (0–1000). Limits top speed/duty regardless of mode. If amps won't rise, this is usually why — raise it.
Stall trip | Amps ≥ this for this long (RUN modes) → stop + disarm.
Temp / I²t | Temperature trip (controller) and the I²t motor-heat budget (A²·s).
Overtorque backoff | At/above this amps for this long → ramp command down to relieve torque. Suppressed during the lift test.
CREEP kick | Breakaway boost (level · ms) on start-from-stop to overcome static friction.

### Controller config (Advanced profile editor — writes controller RAM, verified)

ALIM | Current limit (0.1 A → 50 = 5.0 A). Foldback holds motor amps at/below this. Current = torque.
MXPF / MXPR | Max power forward/reverse (%). Ceiling on duty = top speed.
RWD | Command-loss watchdog (ms). Serial silence this long → motor stops.
MAC / MDEC | Accel/decel ramps (ms for 0→100 %). Longer = gentler start (less inrush) and softer stop (less regen spike).
OVL / UVL | Over/under-voltage cutoffs (0.1 V). A descending load regenerates and raises bus voltage — a PSU (unlike a battery) can't absorb it. Heavy-lift current sags the supply — set UVL below your worst sag.
ATRIG/ATGA/ATGD | Controller-side amps-trigger: level (0.1 A, below ALIM), action (17 = safety-stop M1), delay (ms). A hardware backstop that survives a host bug.

Profile edits are RAM-only until you Save to flash. A controller reset reverts RAM to flash — the control-drift alarm catches that.

## 6 · Tools

### Characterization sweep

Steps the command up in increments, records the settled amps at each level → a command→amps curve, an estimated breakaway command, and a suggested CREEP kick. Requires ARM; aborts on trip/disarm.

### Guided lift test

Holds a slow command and raises ALIM rung by rung until the motor breaks free (amps drop below the limit), then reports the load current and suggests ALIM ≈ peak×1.3. Works in either direction. Requires ARM; aborts on trip/disarm/over-temp; restores the safe limit on any non-success stop. The hold command must be high enough to drive current up to the limit — if it never reaches the limit, raise the hold cmd (and the speed cap).

### Logging

Always on by default. Full telemetry + every config change, test event, trip, and E-STOP → a timestamped CSV in logs/. Selectable rate (5 Hz / 15 Hz aggressive).

### Advanced graph

Overlay any telemetry (motor A, supply A, power, volts, temp, speed) over time; click a legend chip to toggle a trace.

## 7 · Tuning a loaded roto

An unbalanced (lifting) load draws current that varies with angle — highest while lifting, low/regenerative on the way down. Tune for the peak-lift point.

1. Be on the real supply; fuse & wire for the current.
2. Turn logging to 15 Hz.
3. Run the guided lift test → find peak-lift current.
4. Set ALIM ≈ peak × 1.3 in the profile editor.
5. Run it loaded in CREEP and watch Max temp — stabilising = good, climbing = over the motor's continuous rating.
6. Set the guards (stall above peak-lift, temp, I²t, CREEP kick) and Save to flash.

If it hits the ceiling without lifting, or temp keeps climbing, the answer is more gear reduction or a run/rest duty cycle — not just more current.

## 8 · Reading the telemetry

Motor amps | Winding current = torque. The AT-LIMIT badge = the controller is folding back power to hold the limit.
Supply amps | Current from the supply. Negative = regen (a descending load).
Power out | Actual PWM duty applied. If it's less than your command, foldback is active. If it equals your command, you're not current-limited — a low command is the constraint.
Status | Active command mode (serial), plus STALL, AT-LIMIT, pwr-off flags.
Speed | 0 until an encoder is fitted (open-loop has no motion feedback).

## 9 · Troubleshooting

Armed but not moving | Read the red gate line under the command: DISARMED / DEADMAN / TRIPPED / E-STOP. In JOG use CRUISE for set-and-hold.
Amps won't rise / won't lift | Power out = command & no AT-LIMIT → the speed cap is clamping the command. Raise it so amps climb to ALIM.
I²t trip too soon | Budget too small for a beefy motor — raise it, keep it on (it's your motor-heat proxy), tune by feeling the motor.
CONTROL DRIFT alarm | A controller reset reverted RAM config → Re-apply safe profile, then Save to flash.
Violent break-free feared | Keep ALIM snug (peak×1.3), enable overtorque backoff, gentle MDEC. An encoder makes this precise.

Full project docs: see the repo README and docs/. This guide covers the console.

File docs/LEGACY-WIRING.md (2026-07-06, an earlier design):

# Legacy Wiring — As-Found (DMX → Analog → HDC2450)

> **Scope: LEGACY ONLY.** This documents the *original, field-modified* control rig as
> physically found on the bench — **not** the new ESP32-POE-ISO serial design (see `HARDWARE.md`).
> The harness was field-stripped/rebuilt at Burning Man and is **suspect**; treat every
> connection here as "observed, needs meter confirmation," not "correct."

---

## 1. Legacy signal chain

```
DMX512 (XLR) ─► Northlight "Decode8" ─► analog voltage (0–5V) ─► HDC2450 DB25 (Main / P1) ─► Motor(s)
                8-ch DMX→0-5/0-10V         + signal ground ─────►
                (externally powered)
```

The Decode8 is an 8-channel DMX-to-analog decoder (Northlight Systems, `Decode8.pdf`). Each
DMX slot → one 0–5V or 0–10V output on a screw terminal, plus a common `G`. This is the analog
command path the project **later rejected** in favor of RS232 serial.

---

## 2. HDC2450 Main connector (DB25 / P1) — orientation

Per datasheet **Figure 11 / Table 4** (HDC2450 Motor Controller Datasheet v1.2):

- The connector is a **DB25**. The **13-pin row is pins 1–13**; the **12-pin row is pins 14–25**.
- Molded corner numbers: **1, 13** (13-pin row ends) and **14, 25** (12-pin row ends).
- **As-viewed on the bench:** 13-pin row on **top**, **pin 1 at the left**. Then:
  - Top row, left→right: `1, 2, 3, 4 … 13`
  - Bottom row, left→right: `14, 15, 16 … 25`
- **Cross-check that locks orientation:** the single wired top-row pin is 4th from the left =
  **pin 4 = AnaCmd1** (analog command, Motor 1). A DMX→analog rig driving Motor 1 must use pin 4,
  so the orientation is confirmed by function, not just by counting.

### Relevant HDC2450 DB25 pins (Table 4)

| Pin | Function (default) | Notes |
|-----|---|---|
| 1, 5, 9, 13 | **Ground** | the ONLY grounds on the connector; all in the 13-pin row |
| 2 | RS232 **TxData** | serial (telemetry path in new design) |
| 3 | RS232 **RxData** | serial |
| **4** | **AnaCmd1** — analog cmd, Motor 1 | also RC3 / ANA3 / DIN3 |
| 14, 25 | **+5V Out** | 200 mA total budget; NOT a ground |
| 15 | RCRadio1 | also RC1 / **ANA1** / DIN1 |
| 16 | RCRadio2 | also RC2 / **ANA2** / DIN2 |
| **17** | **AnaCmd2** — analog cmd, Motor 2 | also RC4 / ANA4 / DIN4 |

Absolute max on any analog/digital signal pin: **15V** (Table 6). Analog input usable range:
**0–5.1V** (Table 8). → the Decode8 **must** be jumpered to its **0–5V** range (J2 closed), never 0–10V.

---

## 3. As-found wiring (traced 2026-07-05) — CONFIRMED

Harness traced from the **Decode8 output terminals** (screw terminals 1–8 + `G`) to the HDC2450 DB25:

| Decode8 output terminal | → DB25 pin | HDC2450 function (default) |
|---|---|---|
| **2** | **15** | ANA1 (RCRadio1) |
| **3** | **16** | ANA2 (RCRadio2) |
| **4** | **4**  | **AnaCmd1 → Motor 1** |
| **5** | **17** | **AnaCmd2 → Motor 2** |
| **G** (bottom terminal) | *loose — not landed* | **analog common → belongs on DB25 pin 5 (GND)** |

### Findings

1. **The loose wire = Decode8 `G`, the single analog common for all 8 outputs.** With it
   disconnected, **all four analog inputs float** — the controller has no 0V reference, so every
   command is meaningless. **This is the failure.** *Fix: land Decode8 `G` on **DB25 pin 5**.* One
   wire references all four signals; correct single-point ground (Decode8 is externally powered /
   isolated → no ground loop; consistent with datasheet Note 6).
2. **Both analog-command inputs are driven** — out 4 → pin 4 (AnaCmd1, Motor 1) and out 5 → pin 17
   (AnaCmd2, Motor 2). This is a **two-motor** analog rig.
3. **⚠ Config caveat for pins 15/16 (out 2/out 3).** These are **ANA1/ANA2**, which default to
   **RC-radio** inputs and are **ignored in analog mode** unless the stored controller config
   assigns them an action. So out 4 / out 5 are the real motor commands; out 2 / out 3 are either
   vestigial or depend on a non-default config. Read `~AINA` / `~CPRI` over serial to confirm what
   the controller actually does with ANA1/ANA2 before assuming they matter.

### Bring-back-to-life order
1. Land Decode8 `G` → DB25 **pin 5**.
2. Confirm Decode8 jumpers **J2 closed (0–5V)**, **J3 open (proportional)** — see §4.
3. Power up unloaded, e-stop reachable (§4 fail-safe warning).
4. Drive Decode8 **ch 4** → Motor 1, **ch 5** → Motor 2 should respond.

---

## 4. Decode8 jumper settings required for this to be safe/correct

From `Decode8.pdf`:

| Jumper | Set to | Why |
|---|---|-----|
| **J2** | **Closed = 0–5V** | HDC2450 analog input maxes at ~5V; 0–10V would overrange/damage |
| **J3** | **Open = Dim/proportional** | Closed = relay snap (stop-or-full only); motor needs proportional |
| **J1** | signal-loss behavior — see ⚠ | Open = decays to 0V; Closed = holds last value |

**⚠ Fail-safe gap (inherent to the analog path):** with center-stop mapping
(`0V = full reverse, 2.5V = STOP, 5V = full forward`), **0V is NOT stop — it is full reverse.**
So on DMX loss: J1-open → decoder drives 0V → **full reverse**; J1-closed → **holds last command**.
*Neither Decode8 mode produces a clean stop.* The HDC2450 `^RWD` command-loss watchdog guards the
**serial** port only, not the analog line. This is exactly why the project pivoted to serial. On the
bare legacy rig, keep the motor unloaded and an e-stop reachable — a yanked DMX cable does not stop it.

---

## 5. Verify before trusting (MOTOR POWER OFF)

Buzz continuity from each DB25 pin to the Decode8 screw terminals and record the real map:

- [ ] pin 4  → which Decode8 output channel? (= Motor 1 command)
- [ ] pin 17 → which Decode8 output channel? (confirms dual-motor)
- [ ] pins 15/16 → decoder outputs, or jumpered to decoder `G`?
- [ ] **floating wire → trace far end.** If it lands on Decode8 `G`, it is the missing analog
      ground → terminate on **DB25 pin 5**.
- [ ] Confirm Decode8 jumpers: **J2 closed (0–5V)**, **J3 open (proportional)**.
- [ ] Note the DMX start address set on the decoder.

### Chain integrity check (with serial console attached)
`?AI 1` and `?AI 2` report the mV the controller sees on each analog input. Feed a mid DMX level
(~2.5V expected) and confirm `?AI` tracks the meter — that proves DMX byte → decoder → DB25 → input.

---

## Sources
- Roboteq **HDC2450 Motor Controller Datasheet v1.2** (Jul 20 2010): Figure 11 (connector pin
  locations), Table 4 (Main connector pinout), Table 6 (abs max), Table 8 (I/O signal specs).
- Northlight Systems **8-Channel DMX-to-0–10V Decoder** manual (`docs/Decode8.pdf`).
- Project: `docs/HARDWARE.md`, `docs/serial/SERIAL-CONFIG.md`, `tools/roto-setup/config/hdc2450-analog.json`.

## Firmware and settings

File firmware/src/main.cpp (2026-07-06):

// RA Roto Control — firmware entry point.
// Signal chain: DMX/Art-Net/sACN -> InputMux -> PersonaEngine -> SafetyStage -> SerialController -> HDC2450.
// Safety: we command STOP before enabling the controller, send !G continuously (which also feeds
// the HDC2450's ^RWD watchdog), and an ESP task watchdog resets us into the stop state on a hang.
#include <Arduino.h>
#include <esp_task_wdt.h>

#include "Config.h"
#include "ControlTypes.h"
#include "ConfigStore.h"
#include "SerialController.h"
#include "PersonaEngine.h"
#include "SafetyStage.h"
#include "InputMux.h"
#include "net/NetworkManager.h"
#include "net/ArtnetInput.h"
#include "net/SacnInput.h"
#include "web/WebInterface.h"

static Settings         settings;
static ControlState     state;
static HardwareSerial   HdcSerial(1);        // UART1 -> MAX3232 -> HDC2450 RS232
static SerialController  hdcCtl;
static SafetyStage       safety;
static InputMux          mux;
static ArtnetInput       artnet;
static SacnInput         sacn;
static WebInterface      web;

static uint32_t lastControlUs = 0;
static uint32_t lastCmdMs     = 0;
static uint32_t lastPollMs    = 0;
static uint32_t lastHouseMs   = 0;
static uint32_t bootMs        = 0;
static bool     configured_   = false;       // HDC2450 ^RWD/echo set since last reconnect

static bool estopActive() {
  // Active-low: external pull-up, switch to GND. (Nothing wired -> reads HIGH -> inactive.)
  return digitalRead(pins::ESTOP_IN) == LOW;
}
static void setPwrCtrl(bool on) { digitalWrite(pins::PWRCTRL_EN, on ? HIGH : LOW); }

static void onSettingsChanged() {
  ConfigStore::save(settings);
  safety.setSlew(settings.slewLimit);
  artnet.setUniverse(settings.artnetUniverse);
  // NOTE: changing the sACN universe needs a multicast re-join (listener restart) — TODO Phase 3.
}

void setup() {
  Serial.begin(115200);
  bootMs = millis();

  pinMode(pins::STATUS_LED, OUTPUT);
  pinMode(pins::PWRCTRL_EN, OUTPUT);
  setPwrCtrl(false);
  pinMode(pins::ESTOP_IN, INPUT);

  ConfigStore::load(settings);

  // --- Safety-critical: serial up + command STOP before the controller is powered ---
  hdcCtl.begin(&HdcSerial, pins::HDC_RX, pins::HDC_TX, hdc::BAUD);
  hdcCtl.setCommand(cmd::STOP);
  safety.begin(cmd::STOP, settings.slewLimit);

  mux.begin(&settings);
  NetworkManager::begin(settings, RA_HOSTNAME_DEFAULT);
  if (settings.artnetEnabled) artnet.begin(&mux, settings.artnetUniverse);
  if (settings.sacnEnabled)   sacn.begin(&mux, settings.sacnUniverse);
  web.begin(&state, &settings, &mux, onSettingsChanged);

  esp_task_wdt_init(timing::WDT_TIMEOUT_S, /*panic=*/true);
  esp_task_wdt_add(NULL);

  // Power the controller now that we are already commanding stop (unless E-stopped).
  setPwrCtrl(!estopActive());

  lastControlUs = micros();
  Serial.printf("[RA] %s ready. persona=%s\n", RA_FW_VERSION, toString(settings.persona));
}

void loop() {
  esp_task_wdt_reset();
  const uint32_t nowUs = micros();
  const uint32_t nowMs = millis();

  // --- Control loop (200 Hz) ---
  if (nowUs - lastControlUs >= timing::CONTROL_TICK_US) {
    const float dt = (nowUs - lastControlUs) / 1e6f;
    lastControlUs = nowUs;

    const bool estop = estopActive();
    safety.forceFailSafe(estop);
    if (estop) setPwrCtrl(false);

    InputMux::Selected sel = mux.select(nowMs);
    const float targetCmd = PersonaEngine::toCommand(settings, sel.d);
    const float outCmd    = safety.update(targetCmd, dt, sel.live);

    state.activeSource = safety.inFailSafe() ? CommandSource::FailSafe : sel.src;
    state.normalizedD  = sel.d;
    state.targetCmd    = targetCmd;
    state.outputCmd    = outCmd;
    state.failSafe     = safety.inFailSafe();
    state.overrideOn   = mux.overrideActive();
    state.estopActive  = estop;
  }

  // --- Send command to the HDC2450 (20 Hz; also feeds the ^RWD watchdog) ---
  if (nowMs - lastCmdMs >= hdc::CMD_INTERVAL_MS) {
    lastCmdMs = nowMs;
    hdcCtl.setCommand(state.outputCmd);
  }

  // --- Telemetry poll + (re)configure on reconnect ---
  if (nowMs - lastPollMs >= hdc::POLL_INTERVAL_MS) {
    lastPollMs = nowMs;
    hdcCtl.poll(state.tele);
    state.controllerOnline = hdcCtl.online();
    if (state.controllerOnline && !configured_) { hdcCtl.configure(); configured_ = true; }
    if (!state.controllerOnline) configured_ = false;
  }

  // --- Housekeeping / status ---
  if (nowMs - lastHouseMs >= timing::TELEMETRY_MS) {
    lastHouseMs     = nowMs;
    state.ethLinkUp = NetworkManager::linkUp();
    strncpy(state.ip, NetworkManager::ipString(), sizeof(state.ip) - 1);
    state.uptimeS   = (nowMs - bootMs) / 1000;
    digitalWrite(pins::STATUS_LED, state.failSafe ? ((nowMs / 250) & 1) : HIGH);
  }

  web.loop();
}

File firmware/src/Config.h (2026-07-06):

// Config.h — pin map, constants, and defaults. Encodes the locked hardware decisions.
// Control path: RS232 to the Roboteq HDC2450 (via MAX3232). See docs/HARDWARE.md and CLAUDE.md.
// VERIFY GPIO assignments against your exact Olimex board revision schematic before soldering.
#pragma once
#include <stdint.h>

// ---- Firmware identity -----------------------------------------------------
#define RA_FW_VERSION "0.2.0-serial"
#define RA_HOSTNAME_DEFAULT "ra-roto"

// ---- ESP32-POE-ISO pin map -------------------------------------------------
// Ethernet RMII reserves GPIO 0,12,17,18,19,21,22,23,25,26,27 — NEVER reuse.
// (ESP32-PoE-ISO clocks the PHY on GPIO17; GPIO12 is PHY power.)
namespace pins {
  constexpr uint8_t HDC_TX      = 14;   // -> MAX3232 T1IN  -> DB25 pin 3 (controller RxData)
  constexpr uint8_t HDC_RX      = 13;   // <- MAX3232 R1OUT <- DB25 pin 2 (controller TxData)
  constexpr uint8_t DMX_RX      = 35;   // <- MAX485 RO (optional physical DMX512; input-only)
  constexpr uint8_t PWRCTRL_EN  = 32;   // -> S8050 -> KF0602D SSR (optional remote enable)
  constexpr uint8_t ESTOP_IN    = 39;   // <- E-stop / deadman (optional, input-only, ext pull-up)
  constexpr uint8_t STATUS_LED  = 33;   // -> status LED
}

// ---- Ethernet PHY (Olimex ESP32-POE-ISO) -----------------------------------
namespace eth {
  constexpr int PHY_ADDR  = 0;
  constexpr int PHY_POWER = 12;
  constexpr int PHY_MDC   = 23;
  constexpr int PHY_MDIO  = 18;
  // type = LAN8720, clock = GPIO17 output (set in NetworkManager).
}

// ---- Roboteq HDC2450 serial (RS232 via MAX3232) ----------------------------
namespace hdc {
  constexpr uint32_t BAUD             = 115200; // controller default; set to match Roborun+
  constexpr uint8_t  CHANNEL          = 1;      // we drive Motor 1
  constexpr int      CMD_MAX          = 1000;   // !G command range is -1000..+1000
  constexpr uint32_t WATCHDOG_MS      = 500;    // ^RWD: controller stops if silent this long
  constexpr uint32_t CMD_INTERVAL_MS  = 50;     // send !G at 20 Hz (also feeds the watchdog)
  constexpr uint32_t POLL_INTERVAL_MS = 250;    // telemetry query cadence
  constexpr uint32_t RX_TIMEOUT_MS    = 60;     // per-query response wait
  constexpr uint32_t ONLINE_TIMEOUT_MS= 1500;   // "controller online" if a reply seen within this
}

// ---- Command constants -----------------------------------------------------
namespace cmd {
  constexpr float STOP = 0.0f;   // normalized command for stop (also the fail-safe)
  constexpr float FWD  = 1.0f;   // full forward
  constexpr float REV  = -1.0f;  // full reverse
}

// ---- Networking ports ------------------------------------------------------
namespace net {
  constexpr uint16_t ARTNET_PORT = 6454;
  constexpr uint16_t SACN_PORT   = 5568;
  constexpr uint16_t HTTP_PORT   = 80;
}

// ---- Timing ----------------------------------------------------------------
namespace timing {
  constexpr uint32_t CONTROL_TICK_US   = 5000;   // 200 Hz control loop (slew accuracy)
  constexpr uint32_t SOURCE_TIMEOUT_MS = 2000;   // a source is "stale" after this
  constexpr uint32_t TELEMETRY_MS      = 200;    // web/WS push cadence
  constexpr uint32_t WDT_TIMEOUT_S     = 4;      // ESP task watchdog
}

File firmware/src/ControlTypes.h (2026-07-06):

// ControlTypes.h — shared enums, persisted Settings, live ControlState, Telemetry.
#pragma once
#include <stdint.h>

// DMX personas (see docs/PERSONAS.md). Each encodes direction model, resolution, and range.
enum class Persona : uint8_t {
  FullUni      = 1,  // P1: 1ch 8-bit, 0..+100% forward
  FullUni16    = 2,  // P2: 2ch 16-bit, 0..+100% forward
  SlowHalfUni  = 3,  // P3: 1ch 8-bit, 0..+50%
  SlowQuartUni = 4,  // P4: 1ch 8-bit, 0..+25%
  FullBi       = 5,  // P5: 1ch 8-bit, -100%..stop..+100%
  SlowBi       = 6,  // P6: 1ch 8-bit, +/-25%
  FullBi16     = 7,  // P7: 2ch 16-bit bidirectional
};

enum class CommandSource : uint8_t {
  None = 0, FailSafe, Override, Dmx512, Sacn, Artnet
};

const char* toString(Persona p);
const char* toString(CommandSource s);

// Persisted configuration (stored as a versioned blob in NVS via ConfigStore).
struct Settings {
  uint8_t  version       = 2;      // bump invalidates older/incompatible blobs

  // Control (default = bidirectional: -100% rev / stop / +100% fwd)
  Persona  persona       = Persona::FullBi;
  uint16_t dmxStart      = 1;      // 1..512 (footprint 1 or 2 ch by persona)
  float    multiplier    = 1.0f;   // 0..1 live output scale within persona range
  uint8_t  deadband      = 4;      // DMX counts around center (bidirectional)
  float    slewLimit     = 2.0f;   // command units/sec (full range in 0.5s); 0 = off
  bool     invert        = false;
  // Fail-safe command is always cmd::STOP (0) — the HDC2450 also self-stops via ^RWD.

  // Network
  bool     useStaticIp   = false;
  uint32_t staticIp      = 0;
  uint32_t staticGw      = 0;
  uint32_t staticMask    = 0;
  bool     artnetEnabled = true;
  bool     sacnEnabled   = true;
  bool     dmx512Enabled = false;
  uint16_t artnetUniverse= 0;      // 15-bit port-address (Net<<8 | SubUni)
  uint16_t sacnUniverse  = 1;      // 1..63999
  uint8_t  sacnPriority  = 100;
};

// Telemetry queried back from the HDC2450 over serial.
struct Telemetry {
  bool     valid      = false;
  float    motorAmps  = 0.0f;   // ?A  (channel 1)
  float    batteryV   = 0.0f;   // ?V  (main battery)
  int      tempC      = 0;      // ?T
  uint32_t faultFlags = 0;      // ?FF (bitfield: overheat, overvolt, short, estop, ...)
};

// Live state snapshot for telemetry / web UI.
struct ControlState {
  CommandSource activeSource = CommandSource::FailSafe;
  float    normalizedD    = 0.0f;   // 0..1 input after mux
  float    targetCmd      = 0.0f;   // -1..1 persona output, pre-safety
  float    outputCmd      = 0.0f;   // -1..1 commanded, post-safety (0 = stop)
  Telemetry tele;
  bool     ethLinkUp      = false;
  bool     failSafe       = true;
  bool     overrideOn     = false;
  bool     controllerOnline = false; // HDC2450 answering on serial
  bool     estopActive    = false;
  uint32_t uptimeS        = 0;
  char     ip[16]         = "0.0.0.0";
};

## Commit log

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2026-07-05 Scaffold PlatformIO firmware — compiles clean for ESP32-POE-ISO
    Deterministic core implemented: DacDriver (MCP4725), PersonaEngine (7 personas),
    SafetyStage (fail-safe + slew), InputMux, ConfigStore. Network: ETH bring-up +
    Art-Net/sACN parsers over AsyncUDP. Minimal async web UI + WebSocket telemetry.
    main.cpp drives DAC to fail-safe before anything, task watchdog, 200Hz loop.
    Build: RAM 13.7%, Flash 69.7%.
    [Config.h, ControlTypes.h]
2026-07-05 Default to bidirectional (P5): 0V rev / 2.5V stop / 5V fwd
    Confirmed real-volts 0-5V model (HDC2450 input is 0-5V, center 2.5V=stop;
    NOT 0-10V). No hardware change. Fail-safe 2.5V already = stop.
    [ControlTypes.h, roto_setup.py]
2026-07-06 Pivot control path from analog to RS232 serial
    Replace DAC/op-amp analog stage with serial control of the HDC2450 via MAX3232:
    - SerialController: !G commands, ?A/?V/?T/?FF telemetry, ^RWD command-loss watchdog
    - PersonaEngine now outputs normalized command [-1,1]; SafetyStage in command units
    - ControlState carries real telemetry (amps/volts/temp/faults); web UI shows it
    - Removed DacDriver/SenseAdc; Config/pins switched to UART (GPIO13/14)
    - Docs (CLAUDE, HARDWARE, ARCHITECTURE, PERSONAS, README) updated to serial
    Key win: HDC2450 ^RWD watchdog self-stops motor on command loss (serial-only;
    analog held last voltage). Builds clean: RAM 13.6%, Flash 67.9%.
    [Config.h, ControlTypes.h]
2026-07-06 Add host bench tools, legacy wiring docs, license; publish prep
    - tools/roto-bench: localhost web control console for HDC2450 Motor 1 over serial
    (arm gate, momentary/latched, cap+slew, deadman, E-STOP, overcurrent/stall +
    temperature + I2t auto-trip, telemetry + strip chart + alerts, live RAM profile editor)
    - tools/roto-setup: as-found config catalog + bench-safety manifests (5A limit, RWD, AINA)
    - docs/LEGACY-WIRING.md: reverse-engineered DMX->analog->HDC2450 wiring (Decode8 decoder)
    - LICENSE (MIT), README host-tools section + Phase 1 status, gitignore __pycache__
    [roto_bench.py]
2026-07-06 Operator console: named run modes, motion graphs, inline help
    - Run modes JOG / CRUISE / DRIFT / HOLD (replaces raw momentary/intent toggles);
    DRIFT adds a server-side slow-sweep oscillator (amplitude + period)
    - Two strip charts: commanded motion (speed proxy) + motor current (load), captioned
    - Context 'what to do next' hint line driven by live state
    - Tooltips on controls/stats + a built-in Operator guide (collapsible)
    [roto_bench.py]
2026-07-06 Console: show why output is gated, flash on blocked move, fix drag spring-back
    - Red '⛔ output held at 0 — DISARMED/DEADMAN/TRIPPED/E-STOP' line when you command
    motion but it's gated, so 'armed but not moving' is never a mystery
    - Shake + red flash of the command card when you try to drive while disarmed/tripped/estop
    - Fix: slider was springing to 0 on mouseleave mid-drag; release now binds to document mouseup
2026-07-06 Add control-drift detection, richer drift patterns, Advanced profile section
    - CONTROL DRIFT alarm: watches ALIM/RWD/AINA live vs an expected safe baseline and
    raises a critical alert when they diverge (e.g. after a controller reset reverts RAM).
    One-click 'Re-apply safe profile' restores the baseline.
    - DRIFT patterns: center/bias offset + waveform (sine/triangle/saw), not just centered sine.
    - Profile editor moved into a collapsed Advanced <details> (not open by default), with a
    full plain-English description of every parameter.
    [roto_bench.py]
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2026-07-06 Docs: document the control console + hardware findings; console as a run path
    - tools/roto-bench/README.md (new): run modes + DRIFT patterns, layered safety, control-drift
    detection, Advanced profile editor, 'running the show from this console' viability + vs firmware,
    and a 'what we've figured out' hardware findings section
    - ARCHITECTURE.md: two-control-paths note, roadmap marked (Phase 1-2 proven via console),
    hardware-confirmed facts (115200, ?A/?V scaling, ALIM 5A, ATGA 17, command priority)
    - README.md: status reflects serial control proven via console; console framed as a viable run path
2026-07-06 Legacy-machine portability for the console
    - ui.html: drop ES2020 nullish (??) via a helper; switch fetch -> XMLHttpRequest
    -> runs on Safari 10+ (2016) instead of 13.1+. JS syntax verified with node --check.
    - roto_bench.py: ThreadingHTTPServer fallback -> Python 3.6+ (was 3.7); drop __future__ import.
    - run.sh: portable launcher — finds Python 3.6+, installs pyserial if missing, launches.
    - README: compatibility matrix + 'keep it legacy-safe' guidance for UI edits.
    - ARCHITECTURE: note ESP32 is a follow-up pending parts; console covers running in the meantime.
    [roto_bench.py]
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2026-07-06 Add CREEP mode + characterization logging for slow-loaded operation
    - CREEP run mode: latched slow mode with the current-stall trip suppressed (slow+load looks like
    a stall) — temperature + I2t still guard — plus an anti-stiction breakaway kick on start-from-stop
    (configurable level + duration).
    - Characterization log: ~5 Hz CSV (command, amps, volts, temp, heat, trip state) to logs/, with a
    Start/Stop toggle + live status. For mapping command->amps->motion under load and tuning CREEP.
    - README: slow-loaded section (CREEP + logging now; encoder/gearing as the proper follow-up).
    - gitignore logs/.
    [roto_bench.py]
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2026-07-06 Add guided lift test: step ALIM up under load to find peak-lift current
    - Server state machine holds a slow command and raises ALIM rung by rung until measured
    amps fall below the limit (motor broke free = lifting), then reports the load current.
    - Hard safety: requires ARM; aborts on disarm/estop/trip; auto-stops on over-temp; never
    exceeds the operator's ALIM ceiling; RESTORES the safe start limit on any non-success stop;
    stall-trip suppressed during the test (it sits at the limit by design) while temp+I2t stay live;
    keeps the control-drift monitor in step as ALIM changes; mutually exclusive with the sweep.
    - New endpoint /api/lift; UI card with amps-based inputs, live rung table,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
    [roto_bench.py]
2026-07-07 Profile editor: expose MAC/MDEC (ramps) and OVL/UVL (voltage limits)
    - Whitelist OVL/UVL for writes; read all four over serial for the editor's live 'Now' column.
    - Add rows with plain-English descriptions: accel/decel ramps (inrush + regen), over/under-voltage
    cutoffs (regen-rise and heavy-lift sag). Now tunable live during bring-up, not just via CLI.
    [roto_bench.py]
2026-07-07 Expose more motor telemetry + add a configurable advanced graph
    - Read ?BA (supply amps, signed = regen), ?P (applied power/duty), ?M (controller command),
    ?S (encoder speed), ?FS (status flags incl. STALL and AT-LIMIT — the current-foldback signal).
    - Controller-health table now shows supply amps (+regen tag), power %, ctrl command, speed
    (+needs-encoder hint), status flags, and an AT-LIMIT badge next to motor amps.
    - Advanced graph: overlay any of Motor A / Supply A / Power / Volts / Temp / Speed over time,
    each auto-scaled, live values in a clickable legend to toggle traces. Legacy-safe JS.
    [roto_bench.py]
2026-07-07 Add overtorque backoff: relieve command at the current limit to avoid violent break-free
    - When motor amps sit >= a threshold (or the controller's AT-LIMIT flag is set) for a sustained
    time, gently ramp the command DOWN (via a live scale on src, then the normal slew) so the
    drivetrain can't wind up and release violently. Slow recovery once relieved (no oscillation).
    - Suppressed during the deliberate sweep / lift test; applies in all normal run modes incl. CREEP/HOLD
    where the stall trip is off. Fires earlier + softer than the hard stall trip.
    - UI: enable toggle + amps/ms thresholds, a live '⤵ OVERTORQUE — command relieved to N%' banner, and
    a warn alert. Endpoint /api/backoff.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
    [roto_bench.py]
2026-07-07 Fix lift-test false-positive + stale current limit; log all tests & config changes
    Bug fixes (from bench: 'says lifted but doesn't', 'At current limit 5.0A' while ALIM=100):
    - amp_limit now reports the ACTUAL controller ALIM (from mon/profile), not the hardcoded 5.0 A —
    fixes the misleading alert and the chart limit line.
    - lift-test 'lifted' detection now requires the motor to have actually PINNED at the limit first
    (amps >= 0.9*ALIM). Low amps below the limit no longer read as 'lifted' — they mean the hold
    command is too weak to reach the limit, and the test now says so.
    Event logging (requested): CSV gains an 'event' column; while logging, every config change, lift
    rung/set/end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
    [roto_bench.py]
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2026-07-07 UI: sticky status bar + always-visible E-STOP, hover help mode, guide-in-new-window
    - Sticky top bar (follows scroll): status pill, live amps/cmd, the primary E-STOP (moved here so it's
    always reachable), a Help-mode toggle, and a Guide button.
    - Help/explainer mode: toggle on, then hovering any control shows its explanation in a help strip
    (fixes the ? marks that didn't open). Reuses existing title attributes.
    - Input diagnostics collapsed into a details. Copy button on the logging card (path+status+alerts).
    - Operator guide moved to the top, opens /guide in a new window; inline guide removed.
    (subagent-built, independently validated: node --check, legacy-safe JS, id/endpoint cross-ch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
2026-07-07 DRIFT engine: replace sine oscillator with two-phase (Side A/B speed + time + ramp)
    - New model: hold speed A for time A, ramp to B, hold B for time B, ramp back — repeat.
    State drift_a/ta/b/tb/ramp + live drift_phase (for the UI instrument). Endpoint /api/drift.
    Snapping supported (ramp=0 skips ramp phases). Symmetric drift = A=+X/B=-X, equal times.
    - Removed sine osc_* fields, /api/osc, and the now-unused wave() helper.
    [roto_bench.py]
2026-07-07 Operator-first UI: collapse advanced into Settings, two-phase drift instrument, mode-specific controls
    - Default view is now just: sticky status bar → Motion/load graphs → Drive → Alerts (+ trip banner).
    Everything else (trips, protect, backoff, advanced graph, health, characterization, sweep, lift test,
    profile editor, diagnostics) moved into a collapsed '⚙ Settings & tuning' menu.
    - Two-phase DRIFT instrument: sliders for Side A / Side B speed, hold-time each, ramp; a live bar
    showing both setpoints, the current command, and a phase pill (holding A / ramping / holding B).
    - Set/Zero fixed: slider primary, Zero → 'Stop', exact-speed box only in CRUISE/HOLD/CREEP with 'Go'.
    -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
2026-07-07 Add --sim preview mode: run the full UI with fake telemetry, no hardware
    - --sim runs the console without a serial port, feeding synthetic controller responses (amps from
    command, volts, temp, status, seeded config) so the whole UI renders and behaves for visual review,
    demos, and layout validation. --webport overrides the HTTP port.
    - Used it to render the operator-first redesign in a browser and confirm the layout.
    [roto_bench.py]
2026-07-07 Fix always-visible top bar + hover help (verified in browser)
    - Top bar is now position:fixed (was sticky) so E-STOP + status + live amps/cmd stay visible no matter
    where you scroll; content padding auto-fits the bar height (fitBar on load/resize/help-toggle).
    - Help strip lives in the fixed bar, so it's always visible when help mode is on.
    - Added hover-help text to the controls that had none — mode buttons, speed slider, Go, Reset trip —
    which is why help 'didn't work' when pointing at them. Verified live: scrolling keeps the bar,
    help mode shows each control's explanation.
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2026-07-07 Centralize controls in the top bar; E-STOP isolated far-right; graphs pop-out = graphs only
    - Top bar now holds ARM, Stop, and (conditionally) Clear E-Stop / Reset Trip alongside Help/Guide.
    E-STOP is pushed to the far-right corner (margin-left:auto) — big, bold, always in the same place,
    well separated from the other buttons so it can't be hit by accident. Recovery buttons appear only
    when relevant (Clear E-Stop on e-stop, Reset Trip on trip). Removed the action-button row from the
    Drive card and the Reset button from the trip banner (both now in the bar).
    - Graphs pop-out is now graphs-only: removed the stat tiles and the Export PNG button — the live
    numbers are the separate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
2026-07-07 Current governor (default ON): feather command to ride under the limit, not slam into it
    Replaces the overtorque backoff with a proper closed-loop current governor:
    - Default ON (toggle + '% of limit' in ⚙ Settings). Holds motor amps just under gov_frac × ALIM
    (default 85%) by feathering the command down — fast cut on overshoot, slow recovery underneath.
    So a user commanding full speed into an overcurrent just rides the ceiling smoothly instead of
    slamming the hard limit and tripping. Applies to all drive modes; suppressed during lift/sweep.
    - Stall trip is suppressed while the governor is on (the governor owns current limiting and can
    always feather toward 0, so amps can't run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
    [roto_bench.py]
2026-07-07 Center-zero bidirectional speed slider: fill outward from center, not from the left
    A native range slider fills from its left edge, so at 0 (center = stop) it looked half-full/half-power.
    Now the slider is a custom center-zero control: grey at 0, green fill from center → right for forward,
    amber fill from center → left for reverse, with a center tick and ◀ reverse / stop / forward ▶ labels —
    so the visual matches the actual control movement. Verified in browser at 0 / +40% / −30%.
2026-07-07 Move soft Stop out of the top bar into the drive controls
    E-STOP and a soft 'Stop' side by side in the top bar was confusing (both read as 'stop', very different
    actions). Top bar is now ARM · Help · Guide · E-STOP (+ conditional Clear E-Stop / Reset Trip). The soft
    Stop (command 0, stays armed) now lives under the speed slider in the Drive card, where a bring-to-zero
    belongs. Same #zero handler. Verified in browser.
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2026-07-07 Enforce speed cap visibly + move status to the top bar only
    Speed cap was always enforced in the engine (applied clamped to ±cap in every mode), but the UI gave no
    sign of it — the slider went to 100% while the motor silently capped, and the slider range wasn't tied
    to the cap at init. Now:
    - Slider min/max = ±cap, synced from the engine's cap on load (fixes the init mismatch) and on change,
    so it physically can't exceed the cap in any mode.
    - Exact-speed (Go) clamps over-cap entries and flashes the cap field.
    - '⚠ at speed cap (X%)' feedback line appears when the command is pinned at the cap.
    - Verified: direct API command of 80% with a 30% cap → applied clamped to 30%.
    Also remov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
2026-07-07 HOLD/CREEP: dedicated fine-effort control (direction toggle + zoomed dial + nudges)
    HOLD and CREEP are effort tasks in a narrow low band, where a full -100..+100 slider gives poor
    resolution. Replaced the speed slider/exact-speed box in these modes with an effort panel:
    - Fwd/Rev direction toggle (split direction from magnitude, so all slider travel is the usable band)
    - a magnitude dial scoped 0..cap (full travel = the range you actually use, capped)
    - fine +1/+5 / -1/-5 nudge buttons for precise, repeatable steps
    - a big 'N% fwd/rev' readout ('effort — energy into the drive'); the generic live-cmd readout is hidden
    in these modes (live value stays in the top bar) to avoid two big numbe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
2026-07-07 Consistent Stop + explicit Run for DRIFT (fix: Stop now actually halts the drift)
    Bug: in DRIFT the command came from the oscillator and ignored 'target', so the Stop button (which just
    set target=0) did NOT halt the drift — it kept oscillating. And in HOLD/CREEP, Stop zeroed the motor but
    the effort panel still showed the dialed value, so it was unclear it took effect.
    Added a soft-stop latch:
    - Engine 'stopped' flag forces output to 0 in EVERY mode (incl. DRIFT). /api/stop sets it (stays armed);
    any fresh command (/api/set) or Run drift (/api/drift) clears it. Entering DRIFT latches stopped so the
    animation waits for an explicit Run instead of auto-running.
    - Stop button now calls /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
    [roto_bench.py]
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2026-07-07 Event-readiness: LAN/phone view, spacebar E-STOP, config backup/restore
    - LAN binding: --host / --lan (0.0.0.0) exposes the console to the network; banner prints the phone URL.
    New /remote page (remote.html): a touch-optimized monitor + emergency controls (big E-STOP, Arm toggle,
    Stop, live command/amps/temp/supply, trip/limit banners) for a phone or tablet at the event.
    - Spacebar = E-STOP hotkey in the main console (ignored while typing in a field).
    - Config snapshot: one-tap Backup (captures the controller's current whitelisted config as a restore
    point + downloads a .json) and Restore (writes it back), plus Load-file restore from a saved .json —
    instant recovery if the config d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
    [roto_bench.py]
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2026-07-08 Optional AS5600 encoder: UI enable + debug, gear ratio, real RPM, true-stall detection
    Simplest path: an Arduino/ESP32 reads the AS5600 over I2C and streams angle+RPM over USB serial; the
    console reads that second port.
    - tools/as5600-reader/as5600_reader.ino — bridge firmware: absolute angle, cumulative position, SIGNED
    RPM (direction-aware via unwrap), magnet-detect; streams 'ANG=.. POS=.. RPM=.. MAG=.. STALL=..' @115200.
    - Engine: EncoderReader thread (independent of the motor serial; sensor-only). OPTIONAL add-on —
    enabled/port/ratio set live from the UI (/api/encoder) or at boot (--encoder/--gear); /api/serial_ports
    lists candidates. Gear ratio: fixture RPM = shaft RPM ÷ rat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
    [as5600_reader.ino, roto_bench.py]
2026-07-08 AS5600 mount: parametric OpenSCAD, gap fixed by the print (no sliding)
    Three printed parts: (1) magnet carrier — set-screw cap that holds the diametric magnet on the shaft
    end face, on-axis; (2) sensor holder — a rigid bracket whose board cradle is printed at a FIXED height
    (mount_rise + air_gap) above two FIXED L-bracket bolt holes, so the air gap is a printed dimension, not
    set by sliding/tensioning; (3) gap gauge — a shim exactly air_gap thick to verify the gap on assembly.
    Board is held chip-down with a center window open to the magnet. Fully parametric — [MEASURE] tags on
    shaft/magnet/board/mount_rise. Previewed via headless Blender (Cycles).
    [as5600_mount.scad]
2026-07-08 AS5600 mount v2: built-in gap via 4 corner standoffs; real board (23x23) + magnet (5x2)
    Gap is now set by the SENSOR HOLDER itself, not the L-bracket: four standoff bosses matching the board's
    corner holes hold the AS5600 chip-side-down at air_gap above the magnet, center open (no plastic between
    chip and magnet). Ring around the spinning carrier + arm to a fixed-hole L-bracket foot (retention only).
    Board 23x23, magnet 5x2 diametric, chip centered. Still parametric — [MEASURE] mount_rise + board hole
    spacing. Previewed live in Blender.
    [as5600_mount.scad]
2026-07-08 AS5600 mount: real board hole spacing (16mm c-c, 3.5mm), chip-down gap 2.5mm
    From measured board: holes 16mm center-to-center (12.5mm gap between + 3.5mm dia), 1.5mm from edges of
    the 23mm board. air_gap 2.5mm (magnet->board face) gives ~1mm chip-body clearance, die ~1.3mm off the
    magnet — in-range for the 5mm diametric magnet. Chip-down (SMD parts sit below chip height, so the chip
    is the closest point; best field). Only mount_rise left to measure. Rendered live in Blender.
    [as5600_mount.scad]
2026-07-08 AS5600 mount v3: self-spacing nested design (carrier pilot+shoulder, holder cups over)
    Redesign per intent — the gap is set by the two parts nesting, not the L-bracket:
    - MAGNET CARRIER: shaft cap + a raised PILOT holding the magnet on-axis + a SHOULDER (step to the
    wider body).
    - SENSOR HOLDER: cups over the pilot (running-clearance bore = concentric register, centers the chip
    over the magnet) and its hub bottom SEATS on the shoulder = the spacer that fixes the board air_gap
    above the magnet. Carrier spins under it; they rub at the seat (slow roto ok; thrust washer/bearing
    optional). Board rides the holder which rides the carrier, so the gap holds even if the shaft wobbles.
    - L-br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
    [as5600_mount.scad]
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2026-07-08 AS5600 mount: bump fit clearances to ABS-friendly values
    shaft_fit 0.35->0.45, magnet_fit 0.15->0.25, hub_fit 0.4->0.5 to absorb ABS cooling shrinkage so the
    carrier slides on the shaft, the magnet seats, and the holder spins free on the pilot on the first pull.
    Still tune per printer via the test carrier+gauge.
    [as5600_mount.scad]
2026-07-08 Fix carrier: pilot was floating over the shaft bore (bore wider than pilot)
    The shaft bore (shaft_d + fit = 13.15mm) is wider than the pilot (11mm) and ran up to the pilot base,
    so the pilot/magnet holder had no material connecting it to the shaft-grip body — freestanding. Added
    bore_floor (3mm) so the shaft bore stops below a solid floor that ties the pilot into the body. Verified
    in a Blender cross-section. Project STLs in tools/as5600-reader/stl/ regenerated.
    [as5600_mount.scad]
2026-07-08 Tighten the pilot/bore register so the chip stays centered on the magnet
    hub_fit 0.5 -> 0.25 (radial). The carrier pilot (male) + holder bore (female) is the register that
    concentrically locates the chip over the magnet; 0.5mm radial was too loose (up to 0.5mm chip offset).
    Both parts are printed so ABS shrinkage cancels — the earlier ABS loosening was wrong for this fit.
    ~0.5mm total slop now: centers yet spins. Verified the mating in a Blender cross-section. STLs refreshed.
    [as5600_mount.scad]
2026-07-08 docs: bring documentation up to date with this session's work
    Console (tools/roto-bench/README.md): current governor, soft-stop + DRIFT Run/Stop, enforced+displayed
    speed cap, percentage UI + center-zero sliders, HOLD/CREEP effort control, arm toggle, hover-help + /guide,
    pop-out /graphs & /stats, --lan + /remote phone view, spacebar E-STOP, config backup/restore, --sim, and
    the optional AS5600 encoder settings.
    New tools/as5600-reader/README.md: the optional encoder — I2C->USB bridge firmware, console integration
    (gear ratio -> fixture RPM, true-stall trip), and the nested self-spacing 3D-printed mount. Print-ready
    STLs committed under stl/.
    Top-level (README.md, CLAUDE.md, docs/ARCHITE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
    [as5600_carrier.stl, as5600_gauge.stl, as5600_holder.stl]
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2026-07-11 drift: capture the HOLD command as the drift center (zero position)
    When you enter DRIFT, the command you were on (e.g. your HOLD position) is captured as drift_center, and
    the Side A/B swing now rides on that center (clamped to the speed cap) instead of being absolute. So HOLD
    -> DRIFT makes the held position the drift's zero, and it oscillates around it. Backward-compatible:
    center defaults to 0 (today's absolute drift); entering from a stop captures 0.
    - engine: State.drift_center, captured from 'applied' on DRIFT entry, snapshot exposes it, oscillator
    does src = clamp(drift_center + swing, -cap, cap). New /api/driftcenter?v= to set/zero it without
    starting the drift.
    - ui: 'Center (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
    [roto_bench.py]
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
